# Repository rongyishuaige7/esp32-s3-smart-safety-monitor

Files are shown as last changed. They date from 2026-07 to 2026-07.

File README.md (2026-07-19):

# 基于ESP32-S3的多传感器智能安全监测系统

> 面向嵌入式学习的 ESP32-S3 多传感器监测与低压执行器联动原型：MQ-2/MQ-5 原始 ADC 采样、火焰模块输入、超声波雷达、SSD1306 OLED、本地状态页与分时执行器逻辑。




> [!CAUTION]
> 这是本科软硬件学习原型，**不是火灾报警器、可燃气体报警器、自动灭火系统、通风安全系统、生命安全设备或生产控制设备**。MQ-2/MQ-5 原始 ADC 值、火焰模块输入和代码阈值不能替代人工核实、合规检测、报警送达或紧急处置。遇到真实火情、疑似燃气泄漏或其他危险，请立刻离开风险区域并联系当地专业应急服务。

## 项目资料

相关 EDA 文件已整理，文件处理说明见 [MEDIA_EVIDENCE](docs/MEDIA_EVIDENCE.md)。

## 原型学习范围

- ESP32-S3、ESP-IDF、FreeRTOS 任务与互斥共享状态；
- MQ-2 / MQ-5 的 ADC 原始数据采样与代码阈值/锁存逻辑；
- 数字火焰模块、HC-SR04 超声波、SSD1306 I²C OLED；
- 蜂鸣器、LED、低压水泵、L9110 风扇与两路 SG90 PWM 的分时驱动；
- 构建时内嵌的本地 HTML 状态页和 SSE；

## 任务因果链

```text
MQ-2 / MQ-5 原始 ADC、火焰模块、HC-SR04
  → FreeRTOS 传感器任务与共享状态
  → 代码阈值、锁存和固定时长的教学逻辑
  → OLED / 本地 SSE 状态页
  → LED、蜂鸣器、低压水泵、风扇、舵机（仅受控演示）
```

代码中的“烟雾”“气体”“火焰”“开窗”“水泵”等标签只描述输入和低压原型逻辑；没有任何一个环节被当作真实安全判断、告警送达或自动处置承诺。

## 硬件与 GPIO

| 模块/信号 | GPIO | 接线说明 |
| :-- | --: | :-- |
| MQ-2 AO | 1 | ADC1_CH0；未校准原始值 |
| MQ-5 AO | 2 | ADC1_CH1；未校准原始值 |
| 火焰模块 DO | 4 | 低电平触发 |
| HC-SR04 TRIG / ECHO | 5 / 6 | 5 V ECHO 必须分压/电平转换 |
| 蜂鸣器 / LED | 7 / 15 | 蜂鸣器为低电平有效 |
| 水泵 H 桥 INA / INB | 16 / 17 | 仅低压驱动意图；供电和管路待确认 |
| L9110 风扇 IA / IB | 18 / 8 | 仅低压风扇驱动意图 |
| 窗户 / 雷达舵机 | 9 / 10 | 50 Hz PWM；须独立供电并共地 |
| SSD1306 OLED SDA / SCL | 11 / 12 | I²C `0x3C`、100 kHz 假定 |

查看完整元件、接线和上电风险：[BOM](hardware/BOM.csv)、[接线图](hardware/wiring-diagram.svg)、[硬件与电气说明](HARDWARE.md)。所有实际电压、电流、电机驱动、上拉、电平转换和共地均须按模块资料核对。

## 构建

已验证工具链：**PlatformIO Core 6.1.19**、`espressif32@6.13.0`、ESP-IDF 框架，板型 `esp32-s3-devkitc-1`，Flash 配置 8 MB。

```bash
git clone https://github.com/rongyishuaige7/esp32-s3-smart-safety-monitor.git
cd esp32-s3-smart-safety-monitor
pio run
```

首次构建会下载 PlatformIO 平台、ESP-IDF 框架和交叉工具链。构建时，`tools/embed_web.py` 会从 `main/web/index.html` 在 `.pio/generated/` 构建目录生成 C 数组；生成文件不进入 Git。

一键在隔离副本中运行公开门禁和构建：

```bash
bash scripts/verify.sh
```

若要烧录，先阅读 [HARDWARE.md](HARDWARE.md) 和 [构建说明](docs/VERIFICATION.md)。**首次通电时不要连接水泵、风扇、舵机或任何高风险负载；原型启动自检会依次驱动这些接口。**

## 本地网络状态页

公开源码刻意不携带固定 SSID 或密码，默认也不会启动 Wi-Fi/HTTP。

只有在隔离可信测试网络中，才可执行：

```bash
cp main/local_config.example.h main/local_config.h
# 编辑 main/local_config.h，填写仅用于本地测试的热点名称和至少 8 位密码
pio run
```

`main/local_config.h` 已被 Git 忽略，不得提交、截图或写入日志。启用后固件提供本地 WPA2 SoftAP、`/` 页面和 `/api/status` SSE；它**无认证、没有 TLS、没有设备身份、没有访问控制**，不得暴露公网。状态页展示设备当前传送的原始样本和软件状态。

## 阈值与执行器逻辑

代码使用以下原始 ADC 阈值：

| 逻辑项 | 源码常量 | 默认值 | 说明 |
| :-- | :-- | --: | :-- |
| MQ-2 一级 / 二级 / 三级 | `THRESHOLD_SMOKE_LEVEL1/2/3` | 800 / 1500 / 2200 | 原始 ADC 教学阈值。 |
| MQ-5 原始值 | `THRESHOLD_GAS_PPM_RAW` | 2000 | 原始 ADC 值，不是 ppm。 |

阈值和定时只应用于教学逻辑。改动它们后需要重新检查电气接线、受控低压演示与所有文档，不得将“水泵/风扇启动”描述为灭火或安全处置成功。

## 目录

```text
main/                  ESP-IDF 应用、传感器、执行器、OLED 与本地状态页
main/local_config.example.h  本地热点配置模板；真实 local_config.h 不入库
hardware/              BOM 与源码推导的接线边界图
docs/                  来源、状态、验证、协议和 GitHub 元数据
scripts/               Secret scan、发布结构检查与一键验证
tests/                 无硬件源码契约测试
.github/workflows/     固定依赖的 CI 构建与 Artifact 证据
```

## 注意事项

- `font_glcd.c` 包含 Adafruit GFX 的经典 5×7 字体数据，相关声明见 [第三方说明](THIRD_PARTY_NOTICES.md)；
- CI Artifact 用于保留构建记录，保留期为 14 天。

## 许可证与学术诚信

Rongyi 原创整理和源码使用 [MIT License](LICENSE)。ESP-IDF、FreeRTOS、Adafruit 字体和其他上游组件仍遵循各自许可证与声明，见 [第三方说明](THIRD_PARTY_NOTICES.md)。

欢迎学习、复现和二次开发；请注明来源，不要将本仓直接冒充为自己的毕业设计成果。使用者须自行对接线、测试、合规和任何现实风险负责。

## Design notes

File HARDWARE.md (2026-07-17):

# 硬件与电气边界

本文仅记录当前公开源码中的接口和默认逻辑，不是实物接线证明，**不是 PCB 原理图**，也不是消防/燃气设计审查或产品规格书。当前公开提交尚未重新在实物上烧录和复测。

## 源码接口表

| 子系统 | 模块/信号 | ESP32-S3 GPIO | 源码事实与边界 |
| :-- | :-- | --: | :-- |
| 烟雾采样 | MQ-2 AO | 1（ADC1_CH0） | `PIN_MQ2_ADC_GPIO=1`；阈值是未校准的 ADC 原始值，不是烟雾浓度、法规阈值或可靠报警证据。 |
| 可燃气体采样 | MQ-5 AO | 2（ADC1_CH1） | `PIN_MQ5_ADC_GPIO=2`；原始 ADC 值不等于 ppm，需按具体模块、预热和环境标定。 |
| 火焰模块 | 数字输出 | 4 | `PIN_FLAME_GPIO=4`，源码按低电平为触发；传感器的方向性、抗光干扰和有效范围未复测。 |
| 超声波雷达 | HC-SR04 TRIG / ECHO | 5 / 6 | ECHO 若为 5 V 逻辑必须通过分压或电平转换，不能直接接入 3.3 V GPIO。 |
| 声光提示 | 蜂鸣器 / LED | 7 / 15 | 蜂鸣器逻辑为低电平有效；不要直接把未知电流负载接在 GPIO。 |
| 水泵驱动 | H 桥 INA / INB | 16 / 17 | 源码默认双线驱动；水泵电源、续流、电流、管路和共地均待实物确认。 |
| 通风 | L9110 IA / IB | 18 / 8 | 仅代表低压风扇驱动意图；不能据此推断风量、散热或气体处置效果。 |
| 舵机 | 窗口 / 雷达扫描 | 9 / 10 | 两路 LEDC 50 Hz PWM；舵机须使用独立、足够的低压供电并与 ESP32 共地。 |
| I²C 显示 | SSD1306 SDA / SCL | 11 / 12 | 地址按 `0x3C`、100 kHz 假定；模块地址、分辨率、上拉和显示行为未复测。 |

## 上电与控制边界

- ESP32-S3 GPIO 是 3.3 V 逻辑；所有模块必须共地，5 V 数字输出不得直接进入 GPIO。
- MQ-2/MQ-5 加热丝、电机、泵、风扇和舵机都可能引入较大电流、浪涌、反电动势和噪声。它们需要与控制器分开的、按实际规格设计的供电/驱动/保护，不能由 USB 或 GPIO 直接承担。
- 固件启动会执行 LED、蜂鸣器、两路舵机、风扇、水泵和传感器读取的顺序自检。**首次上电或接线调整时，请先断开水泵、风扇、舵机等执行负载，或使用受控低压测试条件。**
- `app_config.h` 的定时、阈值、锁存与分时上电只描述教学原型逻辑，不代表经验证的安全策略、响应时限或故障安全设计。
- 公开源码默认不启动 Wi-Fi/HTTP。若在本地复制 `main/local_config.example.h` 为被忽略的 `main/local_config.h` 并填写热点信息，才会创建 WPA2 SoftAP 和状态页；服务无认证、无 TLS，不得暴露到公网，只能用于隔离可信本地测试网络。

## 不可作出的结论

此项目不是火灾报警器、可燃气体报警器、自动灭火系统、通风安全系统、家庭安防产品、生命安全设备或生产控制设备。它不具备传感器标定、冗余、失效检测、认证、联动许可、断电策略、告警送达、长期稳定性或法规符合性证据。

当前只可表述为：**源码来源已确认；公开候选的硬件无关门禁和 ESP32-S3 固件构建可被验证；实物和所有安全相关行为仍待按精确 commit 重新复测。**

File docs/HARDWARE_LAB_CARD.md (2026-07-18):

# Hardware Lab 索引卡片草案

## 名称

```text
基于ESP32-S3的多传感器智能安全监测系统
```

## 摘要

```text
ESP32-S3 多传感器监测教学原型，包含 MQ-2/MQ-5 原始采样、火焰与超声波输入、OLED、本地状态页和低压执行器分时逻辑。
```

## 平台

```text
ESP32-S3 · ESP-IDF · PlatformIO · FreeRTOS · MQ-2 · MQ-5 · SSD1306 · HC-SR04
```

## 真实状态口径

```text
源码来源、公开净化、无硬件源码契约与 ESP32-S3 固件构建已验证。
```

## 公开范围与边界

```text
当前未公开实物照片、演示视频、EDA、PCB、Gerber 或制造文件；已公开 BOM、源码推导接线边界图、来源、协议、状态与验证说明。固定热点密码不公开；用户本地启用的 SoftAP/SSE 无认证、无 TLS。该原型不是火灾/燃气报警、自动灭火、通风安全或生命安全设备。
```

填入 Hardware Lab 前，必须将 `head_sha`、固定 Actions URL 与最终公开仓 default-branch exact HEAD 同步；线上 CI 完成前不得写成构建证据已通过。

- **项目素材：** 已补充项目照片、界面截图和相关资料；范围和版本差异见 [`MEDIA_EVIDENCE.md`](MEDIA_EVIDENCE.md)。

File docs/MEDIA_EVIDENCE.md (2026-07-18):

# 项目素材说明

> 整理日期：2026-07-18

## 文件来源与处理

- 本地 Hardware Lab 素材中心保留原始文件；本仓库收录适合公开展示的处理后副本。
- 图片已按需要移除元数据、遮盖私有信息或缩放；具体处理方式见下表。

## 已公开文件

| 公开路径 | 拍摄日期 / 来源日期 | 脱敏处理 | 文件说明 |
|:--|:--|:--|:--|
| `hardware/eda/schematic.pdf` | 2026-07-18 提供的导出文件 | 从副本移除 PDF 元数据 | EDA 导出。原理图显示 GPIO9 上只有一个 SG90，而当前源码定义 GPIO9 和 GPIO10 两个舵机；应将该 EDA 视为不完整，不能作为当前接线权威。 |
| `hardware/eda/pcb-preview.pdf` | 2026-07-18 提供的导出文件 | 从副本移除 PDF 元数据 | EDA 导出。原理图显示 GPIO9 上只有一个 SG90，而当前源码定义 GPIO9 和 GPIO10 两个舵机；应将该 EDA 视为不完整，不能作为当前接线权威。 |
| `hardware/eda/bom-export.csv` | 2026-07-18 提供的导出文件 | 从 UTF-16LE 表格导出转换为 UTF-8 CSV；已省略供应商、店铺和价格字段 | EDA 导出。原理图显示 GPIO9 上只有一个 SG90，而当前源码定义 GPIO9 和 GPIO10 两个舵机；应将该 EDA 视为不完整，不能作为当前接线权威。 |
| `hardware/eda/gerber/` | 2026-07-18 提供的导出文件 | 从副本解包 Gerber/钻孔成员；已省略第三方下单说明文本 | EDA 导出。原理图显示 GPIO9 上只有一个 SG90，而当前源码定义 GPIO9 和 GPIO10 两个舵机；应将该 EDA 视为不完整，不能作为当前接线权威。 |

## 未公开材料

未列于上表的文件没有复制到本仓库。常见原因包括重复或错投文件、私人标识、过时界面语义或接线信息不完整。原始文件仍保留在本地素材中心。

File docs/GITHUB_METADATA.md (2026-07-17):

# GitHub 元数据

## Description

```text
基于 ESP32-S3、MQ-2/MQ-5、OLED 与低压执行器的多传感器智能安全监测教学原型。
```

## Topics

```text
esp32-s3
esp-idf
platformio
freertos
embedded-systems
hardware-project
iot
oled
sensor-monitoring
sse
```

Topics 仅描述技术范围，不表示传感器精度、消防/燃气安全、自动处置、网络安全、实物已验证或生产可用。

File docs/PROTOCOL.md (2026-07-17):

# 本地状态页协议边界

## 前置条件

仅在用户自行创建本地、被 Git 忽略的 `main/local_config.h`，且 SSID 非空、密码至少 8 位时，固件才启动 SoftAP 与 HTTP 服务。公开默认配置不会启动该服务。

## 路由

| 路由 | 方法 | 用途 | 安全边界 |
| :-- | :-- | :-- | :-- |
| `/` | GET | 返回内嵌 HTML 本地状态页 | 无认证、无 TLS；只可用于隔离可信本地网络 |
| `/api/status` | GET / SSE | 每秒发送软件快照 | 无认证、无 TLS；不是执行器反馈、环境安全、报警送达或外部服务状态 |
| 常见图标路径 | GET | 返回 204 以减少日志噪声 | 不提供实际图标内容 |

`/api/status` 的字段来自 `g_app_state`：`mq2`、`mq5`、`flame`、`dist`、`smoke_level`、`gas_danger`、`buzzer`、`led`、`pump`、`fan`、`window` 与 `state`。其中：

- `mq2`、`mq5` 是 ADC 原始值，不是浓度或校准读数；
- `state` 是代码分支的 UI 状态，不是安全风险分类；
- `buzzer`、`pump`、`fan`、`window` 是软件意图/状态字段，不是传感器或执行器真实动作反馈；
- 路由没有身份、会话、访问控制、TLS、请求签名、速率限制或审计机制。

请不要将页面、串口或网络抓包中的任何“连接”“正常”“报警”字样用于安全、消防、燃气、生产或人身风险结论。

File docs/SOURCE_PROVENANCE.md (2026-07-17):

# 源码来源与权威副本裁决

## 权威副本

| 对象 | 角色 | 证据 | 处理规则 |
| :-- | :-- | :-- | :-- |
| `/home/rongyi/桌面/智能安全监测系统` | 只读原始工作目录 | 40 个非构建/编辑器文件；含本地 `.pio/` 构建缓存、`.vscode/` 和 `sdkconfig.esp32-s3-devkitc-1` | 不在原目录清理、提交或改写 |
| `/mnt/shared/2026项目/智能安全监测系统.zip` | 只读历史归档 | SHA-256 `c0932ed4497638972aa6a46013bd93a98bfb827acf717ff98befa67e18beb1b9`；38 个源码文件 | 不编辑、不重打包 |
| `/home/rongyi/桌面/esp32-s3-smart-safety-monitor` | 全新公开候选 | 新 Git 历史；所有公开净化和文档仅在此目录进行 | 唯一允许发布的目录 |

公开整理前，ZIP 内的 38 个源码文件与桌面原始树中对应的 38 个文件逐字节一致。桌面原始树额外包含：

- `sdkconfig.esp32-s3-devkitc-1`（本机生成配置）；
- `main/web_index_embed.c`（由 HTML 生成的约 133 KiB C 构建输入）；
- `.pio/` 构建缓存与 `.vscode/` 本机编辑器文件。

这些额外对象都不导入公开候选。原始目录没有可继承的 Git 历史，因此公开仓从干净根目录建立。

## 纳入内容

- 当前 ESP-IDF 应用源码、PlatformIO 配置与公开 `sdkconfig.defaults`；
- 原始的传感器、执行器、OLED、雷达和本地状态页源码；
- 从源码推导的 BOM、GPIO 接口边界图、构建/状态/协议/安全文档；
- 新增的公开安全默认配置、无硬件门禁和测试。

## 发布前排除和净化

- 固定 SoftAP SSID `SafetyMonitor` 与密码：固定密码不进入公开候选。公开源码默认从 `local_config.example.h` 读取空值；只有本地、被忽略的 `local_config.h` 才能启用状态页；
- `sdkconfig.esp32-s3-devkitc-1`、`.pio/`、`build/`、生成的 `web_index_embed.c`、编辑器文件和历史 ZIP；
- 原始演示步骤中“对着传感器喷丁烷/点火”“水泵演示”等危险操作文字；公开文档改为风险与受控低压测试边界；
- 本机路径、私网/热点凭据、实物照片、视频、PCB/EDA、构建二进制和不可审计的历史构建结果。

## 公开硬化

- `platformio.ini` 固定 `espressif32@6.13.0` 与 `esp32-s3-devkitc-1`；
- HTML 嵌入 C 文件改为只在构建目录生成，避免提交大体积生成物；
- 启动网络前检查本地配置，未配置时不启动 SoftAP 或 HTTP；
- 日志不回显 SSID、密码或固定本地 IP；
- 删除浏览器预览时生成伪造传感器数据的 DEMO 模式；预览只显示“未连接设备”；
- 移除页面对 Google Fonts 的远程 `@import`，避免隔离 AP 页面隐式访问第三方字体服务；
- 将网页阈值与 `app_config.h` 同步，并将 UI 文案改为原始样本/教学逻辑而非真实安全结论；
- 通过 README、硬件、安全和协议文件明确电气、网络、误报/漏报与高后果边界。

这些措施不证明原始硬件可靠、安全、无误报/漏报或适于任何现实安全用途。

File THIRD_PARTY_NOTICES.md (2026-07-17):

# 第三方依赖与声明

Rongyi 原创代码及本次公开整理适用 [MIT License](LICENSE)。该许可证不替代 SDK、字体或其他上游组件的许可证、NOTICE、商标和服务条款。

| 组件 | 用途 | 许可证或边界 |
| :-- | :-- | :-- |
| ESP-IDF / FreeRTOS | ESP32-S3 驱动、网络、任务和构建框架 | ESP-IDF 由 PlatformIO `espressif32@6.13.0` 拉取；以 Espressif 当前发布的 Apache-2.0 与组件级声明为准：<https://github.com/espressif/esp-idf> |
| PlatformIO Core | 本地与 CI 构建编排 | 固定为 `6.1.19`；见 <https://platformio.org/> 与 <https://github.com/platformio/platformio-core> |
| Adafruit GFX 经典 5×7 字体 | `main/font_glcd.c` 中的 OLED ASCII 字模数据 | 文件头保留来源说明；请遵守 Adafruit GFX 的 BSD 许可与 NOTICE：<https://github.com/adafruit/Adafruit-GFX-Library> |

本仓不复制 ESP-IDF 或 PlatformIO 的完整上游源码。状态页仅使用浏览器/系统自带字体，不再向外部字体服务请求资源。硬件器件型号、模块商标和数据手册也分别属于其权利人。使用者应为自己选择的板卡、模块、驱动、电源和再分发内容单独核对许可与合规性。

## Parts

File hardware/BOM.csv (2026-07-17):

类别 | 器件 | 数量 | 源码/用途 | 采购与电气边界
控制器 | ESP32-S3 DevKitC-1 或兼容开发板 | 1 | ESP-IDF 目标 esp32-s3-devkitc-1 | 精确模组 Flash/USB/稳压待实物确认
气体传感器 | MQ-2 模块 | 1 | GPIO1 ADC 烟雾原始采样 | 常见模块可能需 5V 加热且 AO 电平需确认
气体传感器 | MQ-5 模块 | 1 | GPIO2 ADC 可燃气体原始采样 | 原始 ADC 不等于 ppm；预热和标定待实测
火焰传感器 | 数字火焰传感器模块 | 1 | GPIO4 低电平触发 | 型号/电压/抗环境光能力待确认
距离传感器 | HC-SR04 或兼容模块 | 1 | GPIO5/6 雷达距离 | 5V ECHO 必须分压或电平转换
显示 | SSD1306 I2C OLED | 1 | GPIO11/12 地址 0x3C | 地址/电压/分辨率和上拉待确认
执行器 | 低电平有效蜂鸣器 | 1 | GPIO7 提示 | 型号/驱动电流与额定电压待确认
执行器 | LED 加限流电阻 | 1 | GPIO15 告警指示 | 不得省略限流或直接接未知负载
执行器 | 低压直流水泵与合适 H 桥驱动 | 1 | GPIO16/17 控制 | 电源/续流/管路/水源必须独立受控
执行器 | 低压直流风扇与 L9110 或合适驱动 | 1 | GPIO18/8 控制 | 电机电流和驱动热设计待确认
执行器 | SG90 或兼容舵机（窗户） | 1 | GPIO9 PWM | 须独立供电且共地
执行器 | SG90 或兼容舵机（雷达） | 1 | GPIO10 PWM | 须独立供电且共地
电源 | 隔离且足够裕量的低压电源与连接线 | 按需 | 各模块供电 | 不要用 GPIO 或未知 USB 口直接驱动执行器

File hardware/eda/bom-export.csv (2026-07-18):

name | designator | footprint | quantity | part_number | manufacturer
水泵模块 | CN1 | CONN-TH_B2B-XH-A-LF-SN | 1 | - | JST Sales America
发光二极管 | D1 | 发光二极管LED | 1 | 1N4007W | BLUE ROCKET
L9110风扇模块 | H1 | HDR-4X1/2.54 | 1 | Header-Female-2.54_1x4 | ReliaPro
0.96寸OLED屏幕 COPY | M1 | OLED封装1 | 1 |  | 泉源电子
220Ω | R2 | RES-TH_BD6.0-L17.5-P21.50-D0.8 | 1 | KNP5WS-22Ω±5% T | CCO(千志电子)
MQ2模块 | U1 | MQ2模块 | 1
MQ5模块 | U2 | MQ2模块 | 1
火焰传感器 | U3 | 火焰传感器封装 | 1
SG90 | U4 | SG90 | 1
HC-SR04模块 | U5 | HC-SR04模块 | 1
有源蜂鸣器模块 | U6 | 有源蜂鸣器模块 | 1
果云版ESP32-S3-N16R8 | U7 | 张小黑-ESP32S3-果云版 | 1 | zhangxiaohei | zhangxiaohei

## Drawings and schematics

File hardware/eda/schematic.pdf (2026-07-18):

## LED

## SG90舵机

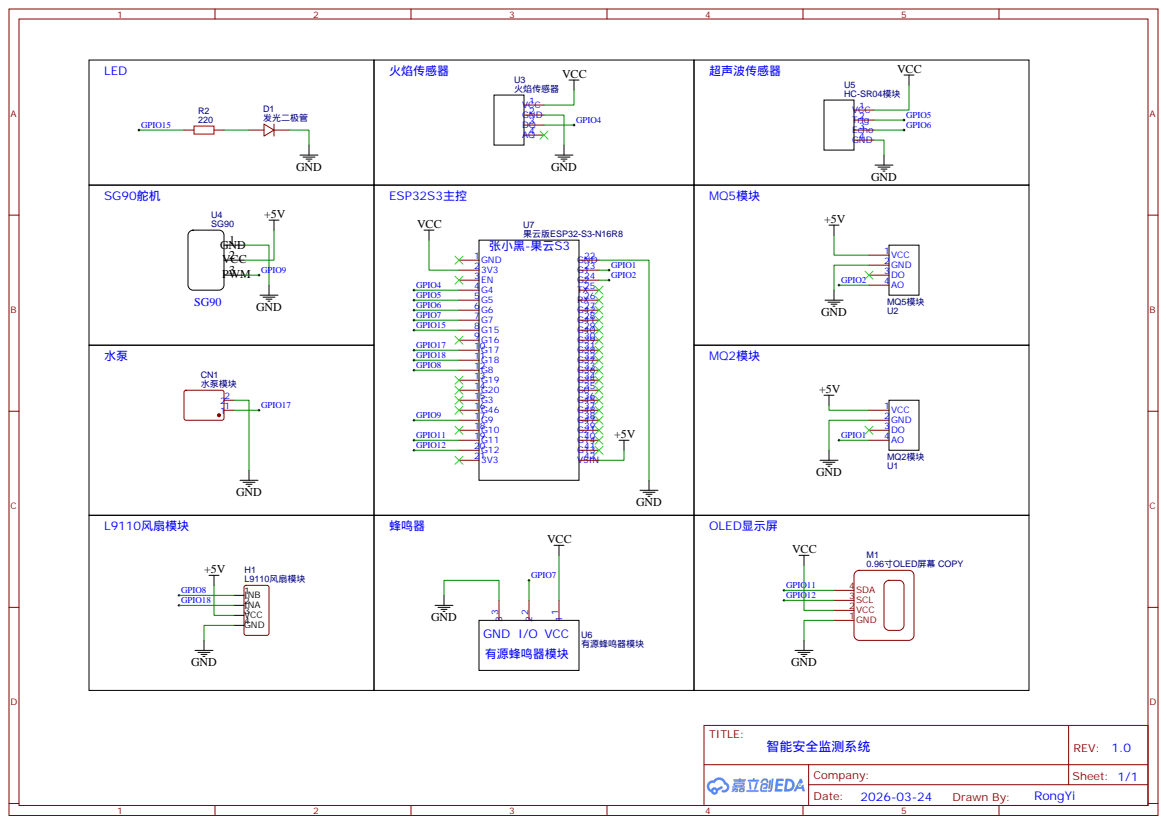
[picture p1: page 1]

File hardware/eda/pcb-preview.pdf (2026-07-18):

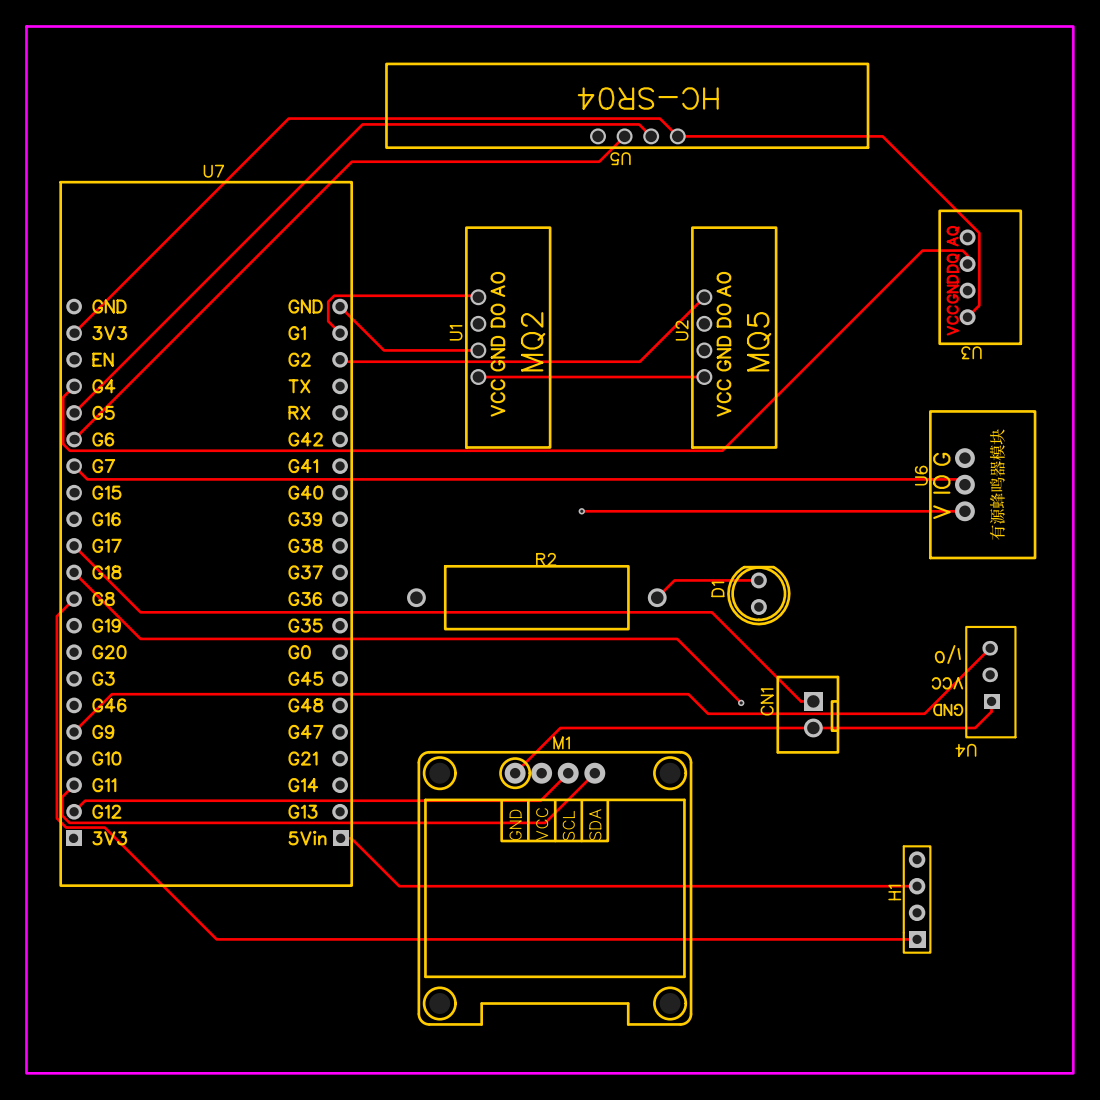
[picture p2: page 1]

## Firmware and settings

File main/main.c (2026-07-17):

/**
 * @file main.c
 * @brief ESP32-S3 智能安全监测：FreeRTOS 任务、共享状态、启动流程。
 */
#include "app_config.h"
#include "sensor_adc.h"
#include "sensor_mq2.h"
#include "sensor_mq5.h"
#include "sensor_flame.h"
#include "sensor_ultrasonic.h"
#include "actuator_ctrl.h"
#include "servo_ctrl.h"
#include "motor_ctrl.h"
#include "alarm_logic.h"
#include "oled_display.h"
#include "radar_scan.h"
#include "web_server.h"

#include "esp_log.h"
#include "freertos/FreeRTOS.h"
#include "freertos/task.h"
#include <string.h>
#include <stdio.h>

static const char *TAG = "main";

app_state_t g_app_state;
SemaphoreHandle_t g_app_state_mutex;

/* ------------------------------------------------------------------ */
/*  自检：在创建 FreeRTOS 任务之前执行一次。
 * 会顺序驱动 LED、蜂鸣器、舵机、风扇与水泵；首次上电前务必断开危险负载
 * 或使用受控低压测试条件。 */
/* ------------------------------------------------------------------ */
static void self_test(void)
{
    ESP_LOGI(TAG, "=============================");
    ESP_LOGI(TAG, " ESP32-S3 Self-Test Starting");
    ESP_LOGI(TAG, "=============================");
    oled_display_msg("SELF TEST", "Starting...");
    vTaskDelay(pdMS_TO_TICKS(1000));

    /* --- 1. LED 闪烁 3 次 --- */
    ESP_LOGI(TAG, "[TEST 1] LED blink x3");
    oled_display_msg("[1] LED", "Blink x3");
    for (int i = 0; i < 3; i++) {
        actuator_led_set(true);
        vTaskDelay(pdMS_TO_TICKS(200));
        actuator_led_set(false);
        vTaskDelay(pdMS_TO_TICKS(200));
    }
    ESP_LOGI(TAG, "  -> OK");

    /* --- 2. 蜂鸣器 0.5 秒 --- */
    ESP_LOGI(TAG, "[TEST 2] Buzzer 0.5s");
    oled_display_msg("[2] Buzzer", "Beep 0.5s");
    actuator_buzzer_set(true);
    vTaskDelay(pdMS_TO_TICKS(500));
    actuator_buzzer_set(false);
    ESP_LOGI(TAG, "  -> OK");

    /* --- 3. 舵机 开窗/关窗（慢速） --- */
    ESP_LOGI(TAG, "[TEST 3] Servo sweep 0->90->0");
    oled_display_msg("[3] Servo", "Sweeping...");
    servo_window_set_open(true);
    vTaskDelay(pdMS_TO_TICKS(800));
    servo_window_set_open(false);
    vTaskDelay(pdMS_TO_TICKS(800));
    ESP_LOGI(TAG, "  -> sweep done");

    /* --- 3b. 雷达舵机 0->90->180->0 扫一轮 --- */
    ESP_LOGI(TAG, "[TEST 3b] Radar servo 0->180->0");
    oled_display_msg("[3b] Radar", "0->180->0...");
    for (int a = 0; a <= 180; a += 10) {
        servo_radar_set_angle((float)a);
        vTaskDelay(pdMS_TO_TICKS(60));
    }
    for (int a = 180; a >= 0; a -= 10) {
        servo_radar_set_angle((float)a);
        vTaskDelay(pdMS_TO_TICKS(60));
    }
    ESP_LOGI(TAG, "  -> radar servo done");

    /* --- 4. 风扇开 2 秒 --- */
    ESP_LOGI(TAG, "[TEST 4] Fan ON 2s");
    oled_display_msg("[4] Fan", "ON 2s -> OFF");
    motor_fan_set(true);
    ESP_LOGI(TAG, "  -> running");
    vTaskDelay(pdMS_TO_TICKS(2000));
    motor_fan_set(false);
    ESP_LOGI(TAG, "  -> OFF");

    /* --- 5. 水泵抽水 1 秒（仅低压受控演示中验证方向） --- */
    ESP_LOGI(TAG, "[TEST 5] Pump drain ON 1s");
    oled_display_msg("[5] Pump", "Drain 1s->OFF");
    actuator_pump_set_drain(true);
    ESP_LOGI(TAG, "  -> ON");
    vTaskDelay(pdMS_TO_TICKS(1000));
    actuator_pump_set_drain(false);
    ESP_LOGI(TAG, "  -> OFF");

    /* --- 6. 超声波测距 3 次 --- */
    ESP_LOGI(TAG, "[TEST 6] Ultrasonic x3");
    oled_display_msg("[6] Ultrasonic", "Measuring...");
    bool us_ok = false;
    for (int i = 0; i < 3; i++) {
        float d = sensor_ultrasonic_measure_cm();
        if (d < 0.f) {
            ESP_LOGW(TAG, "  [%d] timeout", i + 1);
        } else if (d > 400.f) {
            ESP_LOGW(TAG, "  [%d] %.0f cm (out of range)", i + 1, d);
        } else {
            ESP_LOGI(TAG, "  [%d] %.1f cm", i + 1, d);
            us_ok = true;
        }
        vTaskDelay(pdMS_TO_TICKS(200));
    }
    if (!us_ok) {
        ESP_LOGW(TAG, "  !! Ultrasonic: no valid reading (check wiring)");
    }

    /* --- 7. 读取传感器一次并打印 --- */
    ESP_LOGI(TAG, "[TEST 7] Sensor read");
    oled_display_msg("[7] Sensors", "Reading...");
    int mq2 = sensor_mq2_read_raw();
    int mq5 = sensor_mq5_read_raw();
    bool fl  = sensor_flame_read();
    ESP_LOGI(TAG, "  MQ2=%d  MQ5=%d  Flame=%s", mq2, mq5, fl ? "YES" : "no");
    vTaskDelay(pdMS_TO_TICKS(500));

    /* --- 自检结束 --- */
    ESP_LOGI(TAG, "===== Self-test done! Entering monitor loop =====");
    oled_display_msg("Test Done!", "Enter loop...");
    vTaskDelay(pdMS_TO_TICKS(1000));
}

static void sensor_task(void *arg)
{
    (void)arg;
    const TickType_t period = pdMS_TO_TICKS(100);
    for (;;) {
        int mq2 = sensor_mq2_read_raw();
        int mq5 = sensor_mq5_read_raw();
        bool fl = sensor_flame_read();

        app_state_lock();
        g_app_state.mq2_raw = mq2;
        g_app_state.mq5_raw = mq5;
        g_app_state.flame = fl;
        app_state_unlock();

        vTaskDelay(period);
    }
}

static void alarm_task(void *arg)
{
    (void)arg;
    const TickType_t period = pdMS_TO_TICKS(200);
    for (;;) {
        app_state_lock();
        alarm_logic_apply(&g_app_state);
        app_state_unlock();
        vTaskDelay(period);
    }
}

static void radar_task(void *arg)
{
    (void)arg;
    const TickType_t period = pdMS_TO_TICKS(50);
    for (;;) {
        app_state_lock();
        radar_scan_tick(&g_app_state);
        app_state_unlock();
        vTaskDelay(period);
    }
}

static const char *const k_ui_zh[] = {
    [UI_STATE_SAFE] = "\xe5\xae\x89\xe5\x85\xa8",           /* 安全 */
    [UI_STATE_GAS] = "\xe6\x9c\x89\xe6\xaf\x92\xe6\xb0\x94\xe4\xbd\x93", /* 有毒气体 */
    [UI_STATE_SMOKE] = "\xe7\x83\x9f\xe9\x9b\xbe",           /* 烟雾 */
    [UI_STATE_FIRE] = "\xe7\x81\xab\xe7\x84\xb0",           /* 火焰 */
};

static void display_task(void *arg)
{
    (void)arg;
    const TickType_t period = pdMS_TO_TICKS(100);
    static int s_last_ui = -1;
    for (;;) {
        app_state_lock();
        if ((int)g_app_state.ui_state != s_last_ui) {
            s_last_ui = (int)g_app_state.ui_state;
            if (s_last_ui >= 0 && s_last_ui < 4) {
                ESP_LOGW(TAG, "OLED状态: %s", k_ui_zh[s_last_ui]);
            }
        }
        oled_display_render(&g_app_state);
        app_state_unlock();
        vTaskDelay(period);
    }
}

void app_main(void)
{
    g_app_state_mutex = xSemaphoreCreateMutex();
    memset(&g_app_state, 0, sizeof(g_app_state));
    g_app_state.mq2_raw = 0;
    g_app_state.mq5_raw = 0;
    g_app_state.distance_cm = -1.f;
    g_app_state.radar_sweep_deg = 0.f;
    g_app_state.radar_trail_head = 0;
    g_app_state.radar_sweep_dir = 1;
    g_app_state.ui_state = UI_STATE_SAFE;

    ESP_LOGI(TAG, "Smart safety monitor starting");

    ESP_ERROR_CHECK(sensor_adc_init());
    ESP_ERROR_CHECK(sensor_mq2_init());
    ESP_ERROR_CHECK(sensor_mq5_init());
    ESP_ERROR_CHECK(sensor_flame_init());
    ESP_ERROR_CHECK(sensor_ultrasonic_init());
    ESP_ERROR_CHECK(actuator_ctrl_init());
    ESP_ERROR_CHECK(servo_window_init());
    ESP_ERROR_CHECK(servo_radar_init());
    ESP_ERROR_CHECK(motor_fan_init());
    ESP_ERROR_CHECK(oled_display_init());

    /* 先自检：在启动 WiFi 前完成 OLED 提示，避免 I2C 与无线初始化互相干扰 */
    self_test();

    /* 自检后再启动 SoftAP 与 HTTP 服务，再创建传感器等任务 */
    ESP_ERROR_CHECK(web_server_start());

    xTaskCreate(sensor_task, "sensor", 4096, NULL, 5, NULL);
    xTaskCreate(alarm_task, "alarm", 4096, NULL, 6, NULL);
    xTaskCreate(radar_task, "radar", 4096, NULL, 5, NULL);
    xTaskCreate(display_task, "display", 8192, NULL, 4, NULL);

    ESP_LOGI(TAG, "Tasks created");
}

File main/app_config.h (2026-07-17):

/**
 * @file app_config.h
 * @brief 引脚映射、阈值、共享应用状态（ESP32-S3 智能安全监测）。
 */
#pragma once

#include <stdbool.h>
#include <stdint.h>
#include "freertos/FreeRTOS.h"
#include "freertos/semphr.h"

/* -------------------------------------------------------------------------- */
/* GPIO — 传感器                                                              */
/* -------------------------------------------------------------------------- */
#define PIN_MQ2_ADC_GPIO        1   /* ADC1_CH0 */
#define PIN_MQ5_ADC_GPIO        2   /* ADC1_CH1 */
#define PIN_FLAME_GPIO          4
#define PIN_HCSR04_TRIG         5
#define PIN_HCSR04_ECHO         6

/* -------------------------------------------------------------------------- */
/* GPIO — 执行器                                                              */
/* -------------------------------------------------------------------------- */
#define PIN_BUZZER_GPIO         7
#define PIN_LED_ALARM_GPIO      15
#define PIN_PUMP_INA_GPIO       16  /* 水泵驱动板 INA */
#define PIN_PUMP_INB_GPIO       17  /* 水泵驱动板 INB */
#define PIN_L9110_IA_GPIO       18
#define PIN_L9110_IB_GPIO       8
#define PIN_SERVO_WINDOW_GPIO   9   /* LEDC PWM 舵机（开窗） */
#define PIN_SERVO_RADAR_GPIO    10  /* LEDC PWM 舵机（雷达扫描，挂载超声波） */

/* -------------------------------------------------------------------------- */
/* I2C — SSD1306 OLED                                                        */
/* -------------------------------------------------------------------------- */
#define PIN_OLED_SDA_GPIO       11
#define PIN_OLED_SCL_GPIO       12
#define OLED_I2C_ADDR           0x3C
#define OLED_I2C_FREQ_HZ        100000  /* 100kHz，兼容部分 SSD1306 模块 */

/* -------------------------------------------------------------------------- */
/* MQ-2 烟雾阈值（12 位 ADC 原始值 0～4095，按硬件标定）                        */
/* -------------------------------------------------------------------------- */
#define THRESHOLD_SMOKE_LEVEL1  800U
#define THRESHOLD_SMOKE_LEVEL2  1500U
#define THRESHOLD_SMOKE_LEVEL3  2200U

/* 组合规则「浓烟」：烟雾 ≥ 2 级且气体报警同时满足时使用 */
#define THRESHOLD_SMOKE_HEAVY   THRESHOLD_SMOKE_LEVEL2

/* MQ-5 气体阈值（原始 ADC） */
#define THRESHOLD_GAS_PPM_RAW   2000U

/* -------------------------------------------------------------------------- */
/* 超声波                                                                     */
/* -------------------------------------------------------------------------- */
#define HCSR04_MAX_DISTANCE_CM  50.0f
#define HCSR04_TIMEOUT_US       60000  /* 60ms，约 10m 量程，与测试代码一致 */

/* -------------------------------------------------------------------------- */
/* 火焰传感器软件防抖                                                         */
/* sensor_task 周期 100ms；连续 FLAME_DEBOUNCE_COUNT 次采样一致才切换状态。    */
/* 默认 3 → 需持续 300ms 才认定火焰出现/消失，过滤打火机电弧噪声。            */
/* -------------------------------------------------------------------------- */
#define FLAME_DEBOUNCE_COUNT  2

/* -------------------------------------------------------------------------- */
/* 报警解除持续确认帧数                                                        */
/* alarm_task 周期 200ms；连续 ALARM_CLEAR_CONFIRM_COUNT 帧无报警才关执行器。  */
/* 默认 5 → 需持续 1s 无报警才真正关闭，防止信号短暂闪烁导致误关。            */
/* -------------------------------------------------------------------------- */
#define ALARM_CLEAR_CONFIRM_COUNT  5

/* -------------------------------------------------------------------------- */
/* 火焰报警逻辑层锁存时间                                                      */
/* 一旦检测到火焰，alarm_logic 层至少保持报警 FLAME_LATCH_COUNT 帧。           */
/* alarm_task 周期 200ms；默认 25 → 锁存 5s，期间传感器抖动不影响报警状态。   */
/* -------------------------------------------------------------------------- */
#define FLAME_LATCH_COUNT  25

/* -------------------------------------------------------------------------- */
/* 风扇/水泵固定运行时长                                                       */
/* 触发后固定运行 ACTUATOR_RUN_TICKS 帧，之后关闭重新监测，不受传感器读数影响。*/
/* alarm_task 周期 200ms；默认 25 → 固定运行 5s。                             */
/* -------------------------------------------------------------------------- */
#define ACTUATOR_RUN_TICKS  25

/* -------------------------------------------------------------------------- */
/* 执行器分时上电（防浪涌重启）                                                */
/* alarm_task 周期 200ms；每步骤间隔 = ACTUATOR_STAGGER_ALARM_TICKS × 200ms   */
/* 默认 1 → 步骤间隔约 200ms：蜂鸣/LED → +200ms 风扇 → +200ms 舵机           */
/* 若仍重启可调大此值（2 = 400ms 间隔）。                                     */
/* -------------------------------------------------------------------------- */
#define ACTUATOR_STAGGER_ALARM_TICKS  1

/* -------------------------------------------------------------------------- */
/* 雷达尾迹                                                                   */
/* -------------------------------------------------------------------------- */
#define RADAR_TRAIL_LEN  12   /* 尾迹段数，与测试代码一致 */
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

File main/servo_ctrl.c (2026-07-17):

#include "servo_ctrl.h"
#include "app_config.h"
#include "driver/ledc.h"
#include "esp_log.h"

static const char *TAG = "servo";

#define SERVO_TIMER           LEDC_TIMER_0
#define SERVO_MODE            LEDC_LOW_SPEED_MODE
#define SERVO_CHANNEL_WIN     LEDC_CHANNEL_0   /* 窗户舵机 */
#define SERVO_CHANNEL_RADAR   LEDC_CHANNEL_1   /* 雷达舵机 */
#define SERVO_DUTY_RES        LEDC_TIMER_13_BIT
#define SERVO_FREQ_HZ         50

/** SG90 脉宽范围（μs）：500 = 0°，1500 = 90°，2500 = 180° */
#define PULSE_US_0DEG         500
#define PULSE_US_90DEG        1500
#define PULSE_US_180DEG       2500
#define PERIOD_US             (1000000 / SERVO_FREQ_HZ)

/** 窗户舵机：约 500 关窗(0°)，约 1500 开窗(90°) */
#define PULSE_US_CLOSED       PULSE_US_0DEG
#define PULSE_US_OPEN         PULSE_US_90DEG

static uint32_t pulse_to_duty(uint32_t pulse_us)
{
    uint32_t max_duty = (1U << 13) - 1; /* 13 位分辨率，最大 8191 */
    return (pulse_us * max_duty) / PERIOD_US;
}

/** 角度 0～180° 转换为对应脉宽 duty */
static uint32_t angle_to_duty(float deg)
{
    if (deg < 0.f)   deg = 0.f;
    if (deg > 180.f) deg = 180.f;
    uint32_t pulse = (uint32_t)(PULSE_US_0DEG + (PULSE_US_180DEG - PULSE_US_0DEG) * deg / 180.f);
    return pulse_to_duty(pulse);
}

/* ------------------------------------------------------------------ */
/*  舵机1：窗户                                                        */
/* ------------------------------------------------------------------ */
esp_err_t servo_window_init(void)
{
    ledc_timer_config_t tcfg = {
        .speed_mode = SERVO_MODE,
        .duty_resolution = SERVO_DUTY_RES,
        .timer_num = SERVO_TIMER,
        .freq_hz = SERVO_FREQ_HZ,
        .clk_cfg = LEDC_AUTO_CLK,
    };
    ESP_ERROR_CHECK(ledc_timer_config(&tcfg));

    ledc_channel_config_t ch = {
        .gpio_num = PIN_SERVO_WINDOW_GPIO,
        .speed_mode = SERVO_MODE,
        .channel = SERVO_CHANNEL_WIN,
        .intr_type = LEDC_INTR_DISABLE,
        .timer_sel = SERVO_TIMER,
        .duty = pulse_to_duty(PULSE_US_CLOSED),
        .hpoint = 0,
    };
    ESP_ERROR_CHECK(ledc_channel_config(&ch));
    ESP_ERROR_CHECK(ledc_update_duty(SERVO_MODE, SERVO_CHANNEL_WIN));

    ESP_LOGI(TAG, "Servo window on GPIO%d (50Hz LEDC ch0)", PIN_SERVO_WINDOW_GPIO);
    return ESP_OK;
}

void servo_window_set_open(bool open)
{
    uint32_t pulse = open ? PULSE_US_OPEN : PULSE_US_CLOSED;
    uint32_t duty = pulse_to_duty(pulse);
    ledc_set_duty(SERVO_MODE, SERVO_CHANNEL_WIN, duty);
    ledc_update_duty(SERVO_MODE, SERVO_CHANNEL_WIN);
}

/* ------------------------------------------------------------------ */
/*  舵机2：雷达扫描（超声波固定于此舵机转轴）                           */
/* ------------------------------------------------------------------ */
esp_err_t servo_radar_init(void)
{
    /* TIMER_0 在 servo_window_init() 中已配置，此处只注册通道 */
    ledc_channel_config_t ch = {
        .gpio_num = PIN_SERVO_RADAR_GPIO,
        .speed_mode = SERVO_MODE,
        .channel = SERVO_CHANNEL_RADAR,
        .intr_type = LEDC_INTR_DISABLE,
        .timer_sel = SERVO_TIMER,
        .duty = angle_to_duty(0.f),
        .hpoint = 0,
    };
    ESP_ERROR_CHECK(ledc_channel_config(&ch));
    ESP_ERROR_CHECK(ledc_update_duty(SERVO_MODE, SERVO_CHANNEL_RADAR));

    ESP_LOGI(TAG, "Servo radar on GPIO%d (50Hz LEDC ch1)", PIN_SERVO_RADAR_GPIO);
    return ESP_OK;
}

void servo_radar_set_angle(float deg)
{
    uint32_t duty = angle_to_duty(deg);
    ledc_set_duty(SERVO_MODE, SERVO_CHANNEL_RADAR, duty);
    ledc_update_duty(SERVO_MODE, SERVO_CHANNEL_RADAR);
}

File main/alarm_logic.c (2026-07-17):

#include "alarm_logic.h"
#include "actuator_ctrl.h"
#include "motor_ctrl.h"
#include "servo_ctrl.h"
#include "esp_log.h"
#include "freertos/FreeRTOS.h"
#include "freertos/task.h"

static const char *TAG = "alarm";

/*
 * 分时上电防浪涌（有风扇/水泵/舵机任一即启用）：
 *
 * 通用序列（alarm_task 周期 200ms）：
 *   步骤 0        ── 蜂鸣器 + LED 开启
 *   步骤 1~7      ── 维持蜂鸣/LED（等待约 1.6s）
 *   步骤 8        ── 关蜂鸣器 + 启动第一执行器
 *   步骤 9        ── 启动第二执行器（如有）
 *   步骤 10       ── 启动第三执行器（如有）
 *
 * 优先级顺序：舵机 > 风扇 > 水泵
 *   combo(浓烟+气体):  蜂鸣1.6s → 舵机开窗 → 风扇 → 水泵(如LEVEL3)
 *   纯烟雾 LEVEL3:     蜂鸣1.6s → 风扇 → 水泵
 *   纯烟雾 LEVEL2:     蜂鸣1.6s → 风扇
 *   火焰:              蜂鸣1.6s → 水泵
 *
 * s_startup_step 记录已完成的步骤（-1 = 无报警/已复位）。
 */
#define BUZZER_DELAY_STEPS  8   /* 蜂鸣器先响 8×200ms≈1.6s 后再启动下一个执行器 */

static int  s_startup_step   = -1; /* -1: 空闲；否则为分步启动的当前步骤 */
static bool s_running        = false; /* 执行器是否在固定运行期内 */
static int  s_run_ticks_left = 0;  /* 固定运行倒计时，归零时强制关闭 */
static int  s_flame_latch    = 0;  /* 火焰锁存倒计时 */
static int  s_smoke_latch    = 0;  /* 烟雾等级锁存（本次运行周期内只升不降） */

void alarm_logic_apply(app_state_t *s)
{
    int mq2 = s->mq2_raw;
    if (mq2 < 0) { mq2 = 0; }
    int mq5 = s->mq5_raw;
    if (mq5 < 0) { mq5 = 0; }

    /* 火焰锁存：传感器报火焰时重置计时器；计时器>0 时强制视为有火焰 */
    bool flame_raw = s->flame;
    if (flame_raw) {
        s_flame_latch = FLAME_LATCH_COUNT;
    } else if (s_flame_latch > 0) {
        s_flame_latch--;
    }
    bool flame = (s_flame_latch > 0);
    bool gas_danger = (mq5 >= (int)THRESHOLD_GAS_PPM_RAW);

    smoke_level_t sl_raw = SMOKE_LEVEL_NONE;
    if      (mq2 >= (int)THRESHOLD_SMOKE_LEVEL3) { sl_raw = SMOKE_LEVEL_3; }
    else if (mq2 >= (int)THRESHOLD_SMOKE_LEVEL2) { sl_raw = SMOKE_LEVEL_2; }
    else if (mq2 >= (int)THRESHOLD_SMOKE_LEVEL1) { sl_raw = SMOKE_LEVEL_1; }

    /* 烟雾等级锁存：只升不降，报警解除（s_clear_confirm 归零）时才重置 */
    if ((int)sl_raw > s_smoke_latch) {
        s_smoke_latch = (int)sl_raw;
    }
    smoke_level_t sl = (smoke_level_t)s_smoke_latch;

    bool heavy_smoke = (sl >= SMOKE_LEVEL_2); /* 用锁存后的等级判断 */
    bool combo       = gas_danger && heavy_smoke;

    /* ---------- 目标状态（逻辑期望值） ---------- */
    bool want_buzzer  = false;
    bool want_led     = false;
    bool want_pump    = false;
    bool want_fan     = false;
    bool want_win     = false;

    if (flame) {
        want_pump   = true;
        want_buzzer = true;
        want_led    = true;
        sl = SMOKE_LEVEL_3;
    } else if (combo) {
        want_fan    = true;
        want_win    = true;
        want_buzzer = true;
        want_led    = true;
        if (sl >= SMOKE_LEVEL_3) { want_pump = true; }
    } else {
        if (sl >= SMOKE_LEVEL_1) { want_buzzer = true; want_led = true; }
        if (sl >= SMOKE_LEVEL_2) { want_fan    = true; }
        if (sl >= SMOKE_LEVEL_3) { want_pump = true; want_buzzer = true; }
        if (gas_danger)          { want_buzzer = true; want_led = true; }
    }

    bool any_alarm = want_buzzer || want_led || want_pump || want_fan || want_win;
    /* 有任何大功率执行器（风扇/水泵/舵机）就分步上电，避免浪涌 */
    bool need_stagger = want_fan || want_pump || want_win;

    /* ------------------------------------------------------------------ */
    /* 固定运行倒计时：运行中每帧 -1，归零时关闭所有执行器，重回监测状态  */
    /* ------------------------------------------------------------------ */
    if (s_running) {
        s_run_ticks_left--;
        if (s_run_ticks_left <= 0) {
            /* 固定时长到期，强制关闭所有执行器 */
            actuator_buzzer_set(false);
            actuator_led_set(false);
            actuator_pump_set(false);
            motor_fan_set(false);
            servo_window_set_open(false);
            s_startup_step   = -1;
            s_running        = false;
            s_run_ticks_left = 0;
            s_smoke_latch    = 0;
            ESP_LOGI(TAG, "actuator run time expired, all off, resume monitoring");
            goto update_state;
        }
        /* 运行期内推进分步上电（如有） */
        if (s_startup_step >= 0 && s_startup_step < BUZZER_DELAY_STEPS - 1) {
            s_startup_step++;
        } else if (s_startup_step == BUZZER_DELAY_STEPS - 1) {
            /* 蜂鸣器延时结束，关蜂鸣器，启动第一个大功率执行器 */
            actuator_buzzer_set(false);
            if (want_win) {
                servo_window_set_open(true);
                ESP_LOGI(TAG, "stagger: buzzer off, servo open");
            } else if (want_fan) {
                motor_fan_set(true);
                ESP_LOGI(TAG, "stagger: buzzer off, fan on");
            } else if (want_pump) {
                actuator_pump_set(true);
                ESP_LOGI(TAG, "stagger: buzzer off, pump on");
            }
            s_startup_step = BUZZER_DELAY_STEPS;
        } else if (s_startup_step == BUZZER_DELAY_STEPS) {
            /* 第二个大功率执行器 */
            if (want_win) {
                motor_fan_set(want_fan);
                ESP_LOGI(TAG, "stagger: fan=%d", want_fan ? 1 : 0);
            } else if (want_fan && want_pump) {
                actuator_pump_set(true);
                ESP_LOGI(TAG, "stagger: pump on (fan already running)");
            }
            s_startup_step = BUZZER_DELAY_STEPS + 1;
        } else if (s_startup_step == BUZZER_DELAY_STEPS + 1) {
            /* 第三个（仅 combo 且 LEVEL3 同时需要水泵时） */
            if (want_win && want_pump) {
                actuator_pump_set(true);
                ESP_LOGI(TAG, "stagger: pump on (combo+level3)");
            }
            s_startup_step = BUZZER_DELAY_STEPS + 2;
        }
        /* 分步完成后维持，直到计时结束 */
        goto update_state;
    }

    /* ------------------------------------------------------------------ */
    /* 非运行期：检测到报警条件则触发，开始固定运行                        */
    /* ------------------------------------------------------------------ */
    if (!any_alarm) {
        /* 无报警，保持空闲 */
        goto update_state;
    }

    /* 触发：启动固定运行计时器，分步上电 */
    s_running        = true;
    s_run_ticks_left = ACTUATOR_RUN_TICKS;
    ESP_LOGI(TAG, "alarm triggered: run for %d ticks (%dms), stagger=%d",
             ACTUATOR_RUN_TICKS, ACTUATOR_RUN_TICKS * 200, need_stagger ? 1 : 0);

    if (!need_stagger) {
        /* 仅蜂鸣器+LED（LEVEL1 / 纯气体）：立即启动，显式关闭所有大功率 */
        actuator_buzzer_set(want_buzzer);
        actuator_led_set(want_led);
        actuator_pump_set(false);
        motor_fan_set(false);
        servo_window_set_open(false);
        s_startup_step = BUZZER_DELAY_STEPS + 3;
    } else {
        /*
         * 分步上电序列（每帧推进一步，alarm_task 周期 200ms）：
         *
         * combo:   蜂鸣器+LED → 等1.6s → 关蜂鸣+舵机开窗 → 风扇 → 水泵(如需)
         * 非combo: 蜂鸣器+LED → 等1.6s → 关蜂鸣+风扇 → 水泵(如需)
         */
        s_startup_step = 0;
        actuator_buzzer_set(want_buzzer);
        actuator_led_set(want_led);
        ESP_LOGI(TAG, "stagger step0: buzzer/led, next actuator after %d frames", BUZZER_DELAY_STEPS);
    }
    /* 首帧触发后直接进入 update_state，下一帧起由 s_running 驱动分步推进 */
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

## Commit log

2026-07-17 feat: publish ESP32-S3 smart safety monitor prototype
    [BOM.csv]
2026-07-18 docs: add sanitized historical project materials
    [Drill_NPTH_Through.DRL, Drill_PTH_Through.DRL, Drill_PTH_Through_Via.DRL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]
2026-07-18 docs: translate historical material evidence to Chinese
2026-07-18 docs: present project photos as project materials
2026-07-19 docs: 优化项目作品集介绍

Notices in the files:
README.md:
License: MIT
